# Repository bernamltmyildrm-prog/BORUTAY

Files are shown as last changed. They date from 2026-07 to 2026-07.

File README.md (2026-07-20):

<p align="center">
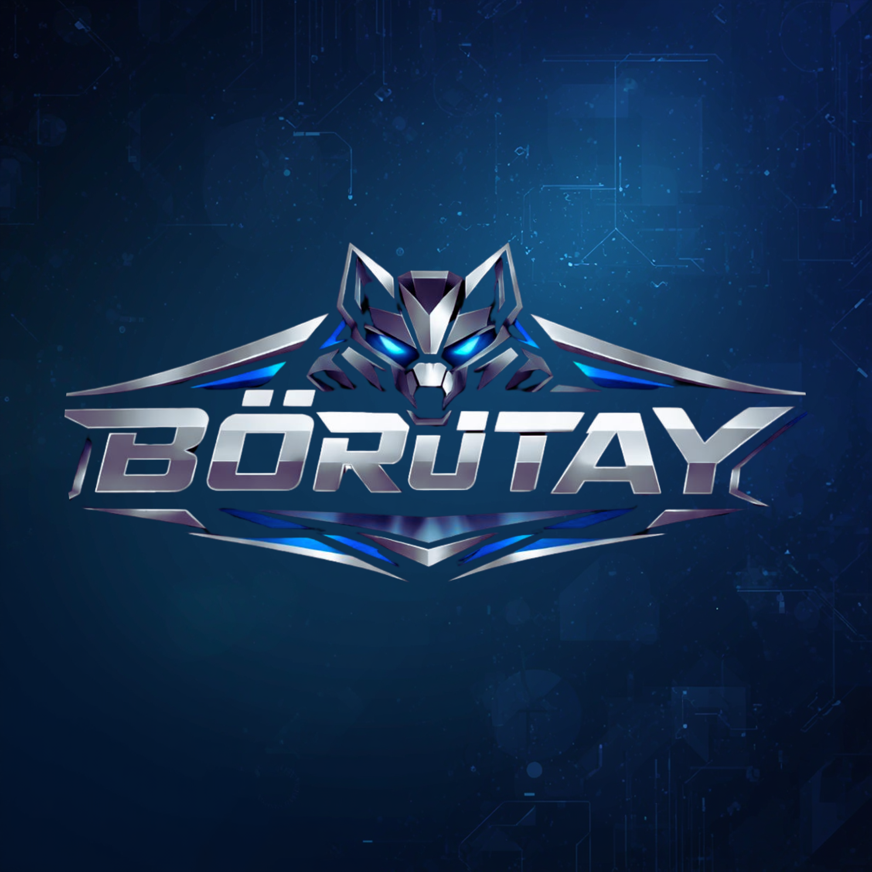
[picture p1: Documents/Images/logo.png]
  
</p>

<h1 align="center">
BÖRÜTAY
</h1>

<p align="center">
Hybrid Quadruped Robot Platform for Disaster Response and Autonomous Robotics
</p>

<p align="center">















</p>

---

# Overview

**BÖRÜTAY** is a modular hybrid quadruped robotic platform developed by the **BÖRÜTAY Team** at **OSTİM Technical University**.

The project has been developed as a research and development platform capable of operating in disaster response scenarios while serving as a flexible testbed for robotics, embedded systems, autonomous navigation and intelligent control algorithms.

The current version features a **2-DOF quadruped architecture** powered by **Raspberry Pi 5**, providing stable walking, real-time monitoring and wireless remote operation.

The next generation of BÖRÜTAY is currently under development and will include:

- 3-DOF Leg Architecture
- Wheel-Leg Hybrid Mobility
- Robotic Arm
- Deneyap Controller Integration
- RFID Module
- OLED Display
- micro-ROS Distributed Architecture
- AI Assisted Navigation

---

## Robot Platform

<p align="center">
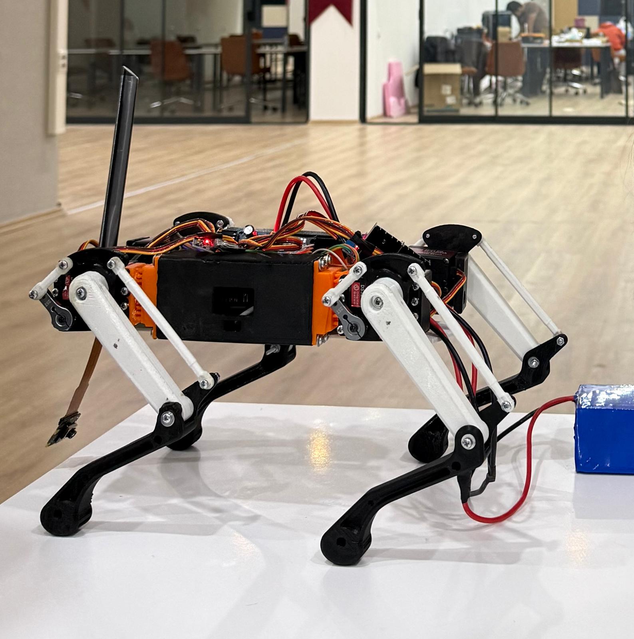
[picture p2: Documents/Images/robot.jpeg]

</p>

---

# Project Objectives

BÖRÜTAY has been designed with the following engineering objectives:

- Develop a modular quadruped robotic platform.
- Support disaster response operations.
- Provide reliable wireless teleoperation.
- Implement embedded Linux based robotic control.
- Integrate computer vision capabilities.
- Develop scalable embedded hardware architecture.
- Prepare the platform for future autonomous navigation.
- Establish a flexible software architecture for future robotic extensions.

---

# Current Features

- ✅ 2-DOF Quadruped Walking
- ✅ Raspberry Pi 5 Main Controller
- ✅ MQTT Communication
- ✅ Live Camera Streaming
- ✅ PyQt6 Ground Control Station
- ✅ Inverse Kinematics
- ✅ Servo Calibration
- ✅ Stable Trot Gait
- ✅ Real-Time Robot Monitoring
- ✅ Modular Software Architecture

---

# Future Features

- 🚧 3-DOF Leg Upgrade
- 🚧 Wheel Assisted Locomotion
- 🚧 Robotic Arm
- 🚧 RFID System
- 🚧 OLED Status Display
- 🚧 Deneyap Controller
- 🚧 micro-ROS
- 🚧 Autonomous Navigation
- 🚧 Object Detection
- 🚧 SLAM
- 🚧 AI Based Decision Making

---

# Hardware

The BÖRÜTAY platform has been designed with a modular hardware architecture that allows new sensors and actuators to be integrated without major software modifications.

## Main Computing Unit

- Raspberry Pi 5
- Raspberry Pi OS (64-bit)
- Python 3

## Embedded Controller (Planned)

- Deneyap Kart
- micro-ROS Node
- Peripheral Management

## Servo Control

- PCA9685 16-Channel PWM Driver
- DS3218 High Torque Digital Servo Motors

## Wireless Communication

- Dual MikroTik RouterBOARD Metal 52ac
- Wi-Fi Communication
- MQTT Protocol

## Vision System

- Raspberry Pi Camera Module

Future Vision Features:

- YOLO Object Detection
- Human Detection
- Obstacle Detection
- Autonomous Tracking

## Sensors

Current

- Pi Camera

Future

- IMU
- RFID Reader
- OLED Display

## Future Mobility

- Wheel Modules
- Robotic Arm
- DC Gear Motors

---

# Software Stack

The software architecture is fully modular, allowing each subsystem to be developed independently.

| Layer | Technology |
|---|---|
| Operating System | Raspberry Pi OS |
| Programming Language | Python |
| GUI | PyQt6 |
| Communication | MQTT |
| Broker | Mosquitto |
| Computer Vision | OpenCV |
| Motion Control | Inverse Kinematics |
| Servo Driver | PCA9685 |
| Future Middleware | micro-ROS |

---

# Repository Structure

```text
BORUTAY
│
├── CAD
│   ├── SolidWorks
│   ├── STL
│   ├── Assembly
│   └── Render
│
├── Documents
│   ├── Graduation_Project
│   ├── TEKNOFEST
│   └── Images
│
├── GUI
│
├── quadruped_pi
│   ├── main.py
│   ├── config.py
│   ├── quadruped.py
│   ├── gait.py
│   ├── leg.py
│   ├── hardware.py
│   ├── robot_listener.py
│   ├── camera_stream.py
│   ├── fake_gyro.py
│   └── utils.py
│
├── README.md
├── LICENSE
└── .gitignore
```

---

# Software Architecture

```
          Ground Control Station
                 (PyQt6 GUI)
                      │
                      │ MQTT
                      ▼
              Raspberry Pi 5
         ┌──────────┼──────────┐
         │          │          │
     Camera      Motion      Hardware
     Module      Control      Driver
         │          │          │
     OpenCV     IK Solver   PCA9685
         │          │          │
         └──────────┼──────────┘
                    │
              Servo Motors
```

---

# Future Embedded Architecture

```
           Ground Control Station
                    │
                 MQTT Broker
                    │
             Raspberry Pi 5
                    │
              micro-ROS Bridge
                    │
             Deneyap Controller
          ┌────────┼─────────┐
          │        │         │
      DC Motors  RFID      OLED
          │
     Robotic Arm
```

---

# Mechanical Design

Current Platform

- 2 Degrees of Freedom per Leg
- 8 Servo Motors
- Aluminum Mechanical Structure
- Modular Body Design

Future Platform

- 3 Degrees of Freedom per Leg
- 12 Servo Motors
- Wheel-Leg Hybrid Mobility
- Integrated Robotic Arm
- Improved Payload Capacity

---

# Communication

Current Communication

- MQTT
- Wi-Fi
- Raspberry Pi Camera Streaming

Future Communication

- micro-ROS
- ROS2 Topics
- Distributed Embedded Nodes
- Autonomous Robot Services

---

# Motion Control

BÖRÜTAY employs a modular locomotion system based on inverse kinematics and gait generation algorithms.

The current locomotion controller has been designed to provide smooth and stable walking while maintaining a lightweight software architecture that can easily be extended for future robotic capabilities.

## Current Motion Features

- Forward / Backward Walking
- Left / Right Turning
- Stand Mode
- Idle (Crouch) Mode
- Servo Calibration
- Smooth Motion Profiles
- Trot Gait
- Adjustable Step Height
- Adjustable Step Length
- Adjustable Gait Period

## Future Motion Features

- 3-DOF Leg Kinematics
- Dynamic Walking
- Terrain Adaptation
- Hybrid Wheel-Leg Motion
- Self Balancing
- Autonomous Locomotion

---

# Inverse Kinematics

Each leg is independently controlled using inverse kinematics.

Current implementation computes:

- Hip Joint Angle
- Knee Joint Angle

Future implementation:

- Hip Roll
- Hip Pitch
- Knee
- Full 3-DOF Kinematics
- Body Pose Compensation

---

# Computer Vision

The Raspberry Pi Camera provides real-time image streaming to the Ground Control Station.

Current capabilities include:

- Live Video Streaming
- Low Latency Monitoring
- Remote Camera View

Future capabilities include:

- Object Detection (YOLO)
- Human Detection
- Obstacle Detection
- QR / AprilTag Recognition
- Autonomous Target Tracking
- Visual Navigation

---

# Ground Control Station

A custom-developed Ground Control Station allows the operator to remotely monitor and control the robot.

Main Features

- Live Camera Stream
- MQTT Communication
- Motion Commands
- Robot Status
- Speed Adjustment
- Stand / Idle Control
- IMU Monitoring (Simulation)
- Object Detection Window
- System Start Function

---

# Ground Control Station Interface

<p align="center">
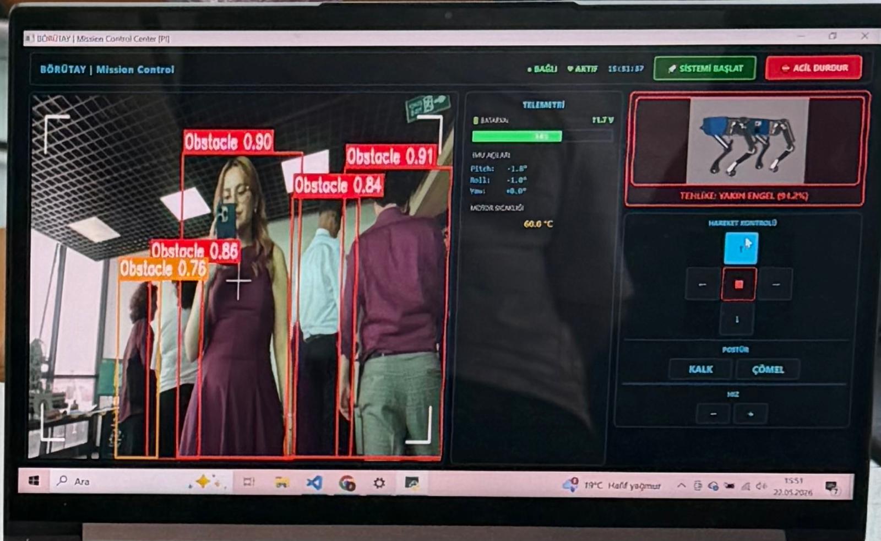
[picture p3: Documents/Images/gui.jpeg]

</p>

The graphical user interface was developed using **PyQt6** and communicates with the Raspberry Pi over the MQTT protocol.

---

# Project Gallery

## Team

<p align="center">
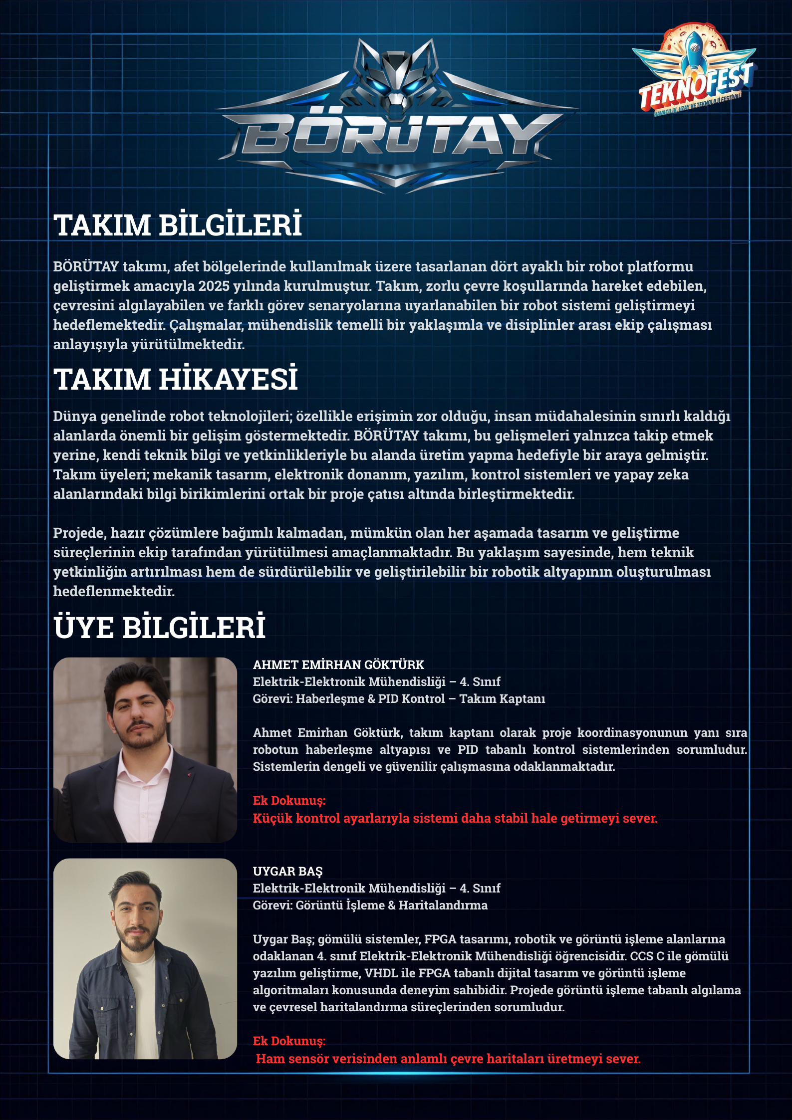
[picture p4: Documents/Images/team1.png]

</p>

<p align="center">
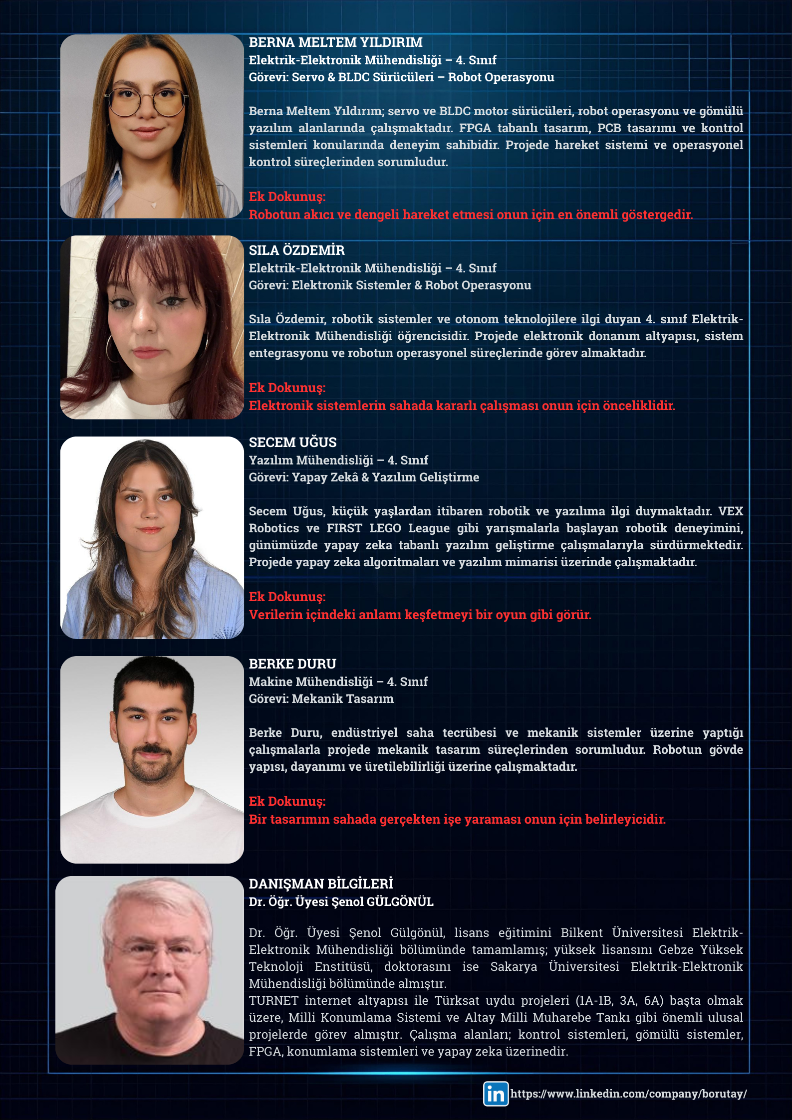
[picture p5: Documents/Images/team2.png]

</p>

---

## Exhibition

The BÖRÜTAY project was presented during the **OSTİM Technical University Graduation Projects Exhibition**, demonstrating the successful integration of mechanical design, embedded systems, wireless communication and quadruped locomotion into a single robotic platform.

The exhibition provided an opportunity to showcase the current capabilities of the platform while collecting valuable feedback for future development.

---

# Installation

Clone the repository:

```bash
git clone https://github.com/bernamltmyildrm-prog/BORUTAY.git
```

Navigate to the project directory:

```bash
cd BORUTAY
```

Install the required Python packages:

```bash
pip install -r requirements.txt
```

---

# Running the Project

## Raspberry Pi

Start the MQTT listener:

```bash
python3 robot_listener.py
```

Start the camera stream:

```bash
python3 camera_stream.py
```

---

## Ground Control Station

Launch the GUI:

```bash
python main.py
```

Once the **System Start** button is pressed, the GUI establishes communication with the Raspberry Pi, activates the robot control interface and starts receiving telemetry and live camera data.

---

# Project Workflow

```
Power ON
    │
    ▼
Connect Raspberry Pi
    │
    ▼
Start robot_listener.py
    │
    ▼
Start camera_stream.py
    │
    ▼
Launch Ground Control Station
    │
    ▼
Press "System Start"
    │
    ▼
MQTT Communication Established
    │
    ▼
Robot Ready
```

---

# Development Roadmap

## Phase 1 — Completed

- [x] Mechanical Design
- [x] Electronic Design
- [x] Raspberry Pi Integration
- [x] Servo Control
- [x] Inverse Kinematics
- [x] Trot Gait
- [x] Camera Streaming
- [x] MQTT Communication
- [x] Ground Control Station
- [x] Graduation Project Prototype

---

## Phase 2 — In Progress

- [ ] 3-DOF Leg Upgrade
- [ ] New Mechanical Design
- [ ] Improved Stability
- [ ] Wheel Integration
- [ ] Robot Arm
- [ ] Deneyap Controller
- [ ] RFID Module
- [ ] OLED Display
- [ ] micro-ROS Integration

---

## Phase 3 — Future Development

- [ ] Autonomous Navigation
- [ ] SLAM
- [ ] Visual Navigation
- [ ] Object Detection
- [ ] AI Decision System
- [ ] Autonomous Mission Planning
- [ ] Multi-Robot Communication

---

# Team

| Team Member | Responsibility |
|---|---|
| **Berna Meltem Yıldırım** | Embedded Systems • Raspberry Pi • MQTT Communication • Servo Control • System Integration |
| **Ahmet Emirhan Göktürk** | Motion Control • Control Algorithms • PID |
| **Uygar Baş** | FPGA • Embedded Systems • Low-Level Software |
| **Sıla Özdemir** | Electronics Design • PCB • Power Electronics |
| **Seçem Uğuş** | Software Engineering • GUI Development |

---

# Academic Advisor

**Dr. Şenol Gülgönül**

Department of Electrical and Electronics Engineering

OSTİM Technical University

---

# Acknowledgements

The BÖRÜTAY Team would like to express sincere gratitude to:

- **OSTİM Technical University**
- **Department of Electrical and Electronics Engineering**
- **Dr. Şenol Gülgönül** for his continuous guidance and academic support throughout the project.
- **OSTİMTech Technology Transfer Office (TTO)** for their valuable support during the development process.

Their encouragement and contributions have played an important role in bringing this project to its current stage.

---

# Contributing

Contributions, suggestions and feedback are always welcome.

If you would like to improve BÖRÜTAY, feel free to open an issue or submit a pull request.

---

# Support the Project

If you find this project interesting or useful, consider giving it a ⭐ on GitHub.

Your support motivates our team and encourages future development.

---

# Connect With Us

Stay connected with the **BÖRÜTAY Team** and follow our journey in robotics, embedded systems, and autonomous technologies.

<p align="center">

<a href="https://www.linkedin.com/company/borutay">

</a>

</p>

---

# License

This project is licensed under the **MIT License**.

See the **LICENSE** file for more information.

---

<p align="center">

## BÖRÜTAY

### *Inspired by our heritage. Engineered for the future.*

**Quadruped Robotics • Embedded Systems**

</p>

<p align="center">

Developed by the **BÖRÜTAY Team**

OSTİM Technical University

</p>

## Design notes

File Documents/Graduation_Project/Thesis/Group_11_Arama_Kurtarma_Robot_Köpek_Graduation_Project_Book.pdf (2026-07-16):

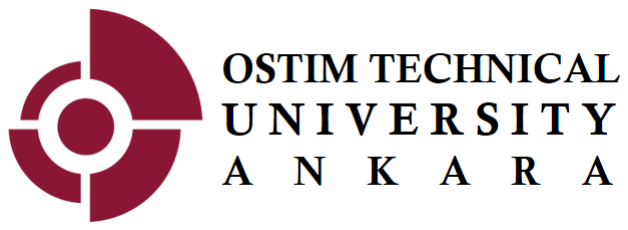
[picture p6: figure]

T.C.

## OSTIM TECHNICAL UNIVERSITY Faculty of Engineering

### Department of Electrical and Electronics Engineering

# Design and Implementation of a Search and Rescue Robot Dog for Disaster Areas

## (Graduation Project I)

### 210202023 Uygar BAŞ 210202015 Sıla ÖZDEMİR 210202009 Berna Meltem YILDIRIM 210202003 Ahmet Emirhan GÖKTÜRK

## Dr. Şenol GÜLGÖNÜL

### December 2025 ANKARA

T.C.

## OSTIM TECHNICAL UNIVERSITY Faculty of Engineering

### Department of Electrical and Electronics Engineering

# Design and Implementation of a Search and Rescue Robot Dog for Disaster Areas

## (Graduation Project I)

### 210202023 Uygar BAŞ 210202015 Sıla ÖZDEMİR 210202009 Berna Meltem YILDIRIM 210202003 Ahmet Emirhan GÖKTÜRK

## Dr. Şenol GÜLGÖNÜL

### December 2025 ANKARA

i

GRADUATION PROJECT APPROVAL FORM

The undergraduate graduation project titled “[Afet Bölgelerinde Arama Kurtarma Amaçlı Robot Köpek Tasarımı ve Uygulaması]”, prepared by [Uygar BAŞ, Sıla ÖZDEMİR, Berna Meltem YILDIRIM, Ahmet Emirhan GÖKTÜRK] under the supervision of

[ Dr. Şenol GÜLGÖNÜL] was examined and accepted as an Undergraduate Graduation Project in terms of its scope and quality.

Supervisor | : Dr. Şenol GÜLGÖNÜL
Jury member 1 | : Dr. Burak YENİPINAR
Jury member 2 | : Prof. Dr. Sinan KIVRAK
Head of the Department | : Prof. Dr. İsmail Hakkı ALTAŞ

ii

FOREWORD

This graduation project was prepared by the students of the Department of Electrical and Electronics Engineering, Faculty of Engineering, OSTIM Technical University, within the scope of Graduation Project I. The project focuses on the design and implementation of a quadruped robot dog intended for search and rescue operations in disaster areas.

We would like to take this opportunity to express our thanks to Asst. Prof. Dr. Senol GULGONUL, our project supervisor and mentor, for the valuable support and guidance that he provided us during the development of our final project. His knowledge and encouragement were critical to successfully completing our graduation project.

We would also like to thank Professor Dr. Ismail Hakkı ALTAS, Head of the Electrical and Electronics Engineering Department, for providing us with an outstanding academic environment that enabled us to successfully complete our graduation project.

Finally, we would like to express our heartfelt appreciation to all our families for their continuous support, patience, and encouragement throughout our academic journey, including the completion of our final project.

December 2025

Uygar BAŞ
Sıla ÖZDEMİR
Berna Meltem YILDIRIM
Ahmet Emirhan GÖKTÜRK

iii

CONTENTS

1.1.1. Global and Regional Impacts of Natural Disasters and the Need for Search and Rescue..1
1.1.2. Evolution of Mobile Robotic Systems: Transition from Wheeled to Legged Architectures

iv

v

vi

ABSTRACT
Search and rescue operations are greatly challenged by natural disasters, such as earthquakes, due to collapsed structures, unstable terrain, and limited access. The traditional rescuer, human, must take many risks and face time constraints when performing rescues in these types of environments. Robotic systems that can safely and effectively operate in abnormal, hazardous, and/or otherwise challenging environments are becoming more desirable in the field.

In this graduation project, the design and implementation of a quadruped search and rescue robot dog for disaster areas is presented. The proposed robot is designed to move effectively on uneven and debris-filled surfaces, where wheeled or tracked robots are insufficient. Owing to its four-legged structure, the robot is capable of maintaining balance and mobility in challenging terrains commonly encountered in disaster zones.

The prototype is composed of three functional categories: mechanical systems, electronics, and embedded systems; these are combined, through integration, to develop one prototype. The stability of the actuators (legs) enables the robot to maintain a consistent position and to walk in a smooth manner. In order to achieve a walking robotic device with balanced mobility, engineers used methods based on PID control. The prototype contains many different types of sensors, including an inertial measurement unit, a Lidar sensor, a camera, and a microphone, which will allow the robot to distinguish potential survivors from ordinary people. All of the sensor readings will be processed in real-time; therefore, except for occasional manual intervention, all tracking will occur automatically. Specific signal detection and locations will be sent wirelessly to a remote command and control facility.

In both cases of being semi-autonomous and fully autonomous, there will be a system with a level of flexibility based on each respective mission. The overall purpose of this project involves increasing the efficiency of search and rescue, improving safety for personnel, and still providing a means for increasing situational awareness in disaster areas. The developed prototype will be a low-cost, easily manufactured robotic solution that supports future research and development in disaster response robotic solutions.

vii

SYMBOLS AND ABREVIATIONS

AI | Artificial Intelligence
CAD | Computer-Aided Design
DOF | Degree of Freedom
IK | Inverse Kinematics
IMU | Inertial Measurement Unit
I2C | Inter-Integrated Circuit

LiDAR Light Detection and Ranging

Li-Po | Lithium-Polymer Battery
MCU | Microcontroller Unit
PID | Proportional–Integral–Derivative
PWM | Pulse Width Modulation
SPI | Serial Peripheral Interface

UART Universal Asynchronous Receiver–Transmitter

W_total Total weight of the robot (N)

W_leg | Load/weight per leg (N)
m | Mass (kg)
g | Gravitational acceleration (m/s^2)
F_leg | Force acting on one leg (N)
F | Applied force (N)
T, τ | Torque (N·m)
r | Lever arm / moment arm (m)
L | Distance from joint axis to load point (m)
σ | Normal stress (Pa)
M | Bending moment (N·m)
c | Distance from neutral axis (m)
I | Area moment of inertia (m^4)
A | Cross-sectional area (m^2)
x, y | Foot position coordinates (m)
l1, l2 | Link lengths (e.g., femur and tibia) (m)

viii

θ1, θ2 | Joint angles (rad or deg)
m_i | Mass of component i (kg)

x_i, y_i Position of component i (m)

x_cm, y_cm Center of mass coordinates (m)

P_total | Total power consumption (W)
P_i | Power of component i (W)
E | Energy (Wh or J)
t | Time / operating duration (h or s)
I_total | Total current consumption (A)
I_servo | Current per servo / servo group (A)

I_control Control electronics current (A)

C | Battery capacity (Ah)

f_control Control loop frequency (Hz)

T_control Control loop period (s)

ix

THE LIST OF FIGURE

Figure 2.3. Calculation

Figure 2.4. Servo Motors and Raspberry Pi 5

Figure 2.5. Jetson Nano and Sensors

Figure 2.8.Wi-fi Modul and Jetson Nano

Figure 3.1. Overall CAD model of the quadruped robot

Figure 3.2. Side view of the robot showing overall height and leg geometry

Figure 3.3. Leg segment configuration illustrating coxa, femur, and tibia

Figure 3.4. Waveshare Jetson Orin NX 16GB AI kit (WiFi)

Figure 3.5. Raspberry Pi 5 single-board computer

Figure 3.6. PCA9685 16-Channel I2C PWM servo driver board

Figure 3.7. Arducam 2.3 MP AR0234 camera module

Figure 3.8.RPLIDAR A2M8 360° LiDAR sensor

Figure 3.9. MG996R metal-gear digital servo motor

Figure 3.10. Power distribution and battery system architecture

Figure 3.11.System hardware layout and internal component placement within the chassis

Figure3.12. The TP-Link Archer T4U dual-band Wi-Fi adapter

Figure 3.13. Software architecture and data flow diagram

Figure 4.1. Simplified kinematic representation of a single robot leg (links and joints)

Figure 4.2. Coordinate frame and foot position definition used in inverse kinematics

Figure 4.3. Geometric inverse kinematics diagram for a two-link planar leg model

Figure 4.4. Inverse kinematics algorithm flow diagram (input: foot position, output: joint

angles)

Figure 4.5. Example foot trajectory and corresponding joint angle variation (theoretical

output)

x

THE LIST OF TABLES

Table 1.1. Work–Time Schedule

Table 1.2. Risk Analysis and Alternative Plans

Table 1.3. Distribution of Work Packages

Table 3.1. Component List and Economic Analysis

THE LIST OF EQUATIONS

Equation (1): Load Distribution per Leg

Equation (2): Static Load Calculation per Leg

Equation (3): Servo Motor Torque Equation

Equation (4): Required Joint Torque Calculation

Equation (5): Bending Stress Equation

Equation (6): Inverse Kinematics Equation for Joint Angle θ₂

Equation (7): Inverse Kinematics Equation for Joint Angle θ₁

Equation (8): Total Current Consumption Equation

Equation (9): Battery Operating Time Estimation

Equation (10): Inverse Kinematics Intermediate Variable (D)

1.INTRODUCTION

### 1.1. General Information

### 1.1.1. Global and Regional Impacts of Natural Disasters and the Need for Search

and Rescue

Natural disasters have been part of human existence since there have been humans-

causing great turmoil both socially and economically, as well as demographically.

While you cannot stop a natural disaster from occurring, you can lessen its effect.

Increased frequency and destructiveness of natural disasters are a direct result of factors

such as global warming, urban sprawl, increased population, and tectonic activity. The

total cost to the world from natural disasters in the last 20 years has been in the trillions

of dollars according to the United Nations Office for Disaster Risk Reduction (UNDRR).

In addition, many hundreds of millions of people have died or lost their homes due to

natural disasters. Because of its geographical location on the Alpine-Himalayan seismic

belt, Türkiye experiences the most seismic activity. The presence of three major fault

lines- North Anatolian Fault, East Anatolian Fault, West Anatolian Fault contributes to

over 90% of Türkiye’s land surface being at risk for earthquakes. Recent Turkish history

such as the 1999 Marmara earthquake, the 2011 Van earthquake and most recently, the

Kahramanmaraş earthquakes of February 6, 2023 show the real vulnerability of the

building stock of Türkiye and the importance of the post-disaster response process.

Labeled the "disaster of the century," the Kahramanmaraş earthquakes have a much

wider geographical range than most previous earthquakes along with an extensive level

of devastation resulting from extreme winter weather that overwhelmed conventional

search and rescue efforts.

One of the main principles in the disaster response process is the "Golden Hours"

factor. The first seventy-two (72) hours immediately following a disaster is the time

period that provides victims under rubble with the highest probability of survival.

Finding victims under rubble during this time frame minimizes life-threatening

conditions such as hypothermia, dehydration, blood loss, and Crush syndrome.

Unfortunately, chaotic collapse of reinforced concrete structures that create impassable

rubble piles, minimize existing survival avenues (triangles of life), create unstable

building components, and pose threats from aftershocks present barriers for search and

rescue teams to access quickly and safely. Moreover, search and rescue are showing diminishing returns as intervention based solely on human effort deteriorates through

physical fatigue, psychological trauma, and safety concerns, which eventually decreases

the rescue effectiveness.

The next step is the use of robotic technology and automated systems. Search and

Rescue Robots are employed to provide services such as mapping, exploration,

audio/video communications, and transporting of medical supplies. They can be sent

into locations that are either unsafe for people to enter or too hazardous for them. These

automated systems gather real-time, precise and useful information, thus limiting the

uncertainty faced by the teams making decisions or conducting rescues following a

disaster strike.

### 1.1.2. Evolution of Mobile Robotic Systems: Transition from Wheeled to

Legged Architectures

When looking at how search and rescue robots have evolved, the first thing to notice

is that "mobility" was the main focus for technology. Search and rescue robots were

created mainly with wheeled and tracked designs.

Wheeled Robots: The main advantages of these vehicles are their high speed, energy

efficiency, and controllability on flat, hard surfaces (e.g., asphalt, concrete, etc.).

However, their mobility is impeded upon encountering objects with a size greater than

that of the wheels or at the point of low-friction ground surfaces (e.g., mud, sand).

Objects like iron bars, piles of debris, and steps/ledges that are common in debris fields

represent major obstacles to wheeled robot navigation.

Tracked Robots: Robots equipped with tank-style locomotion have a much larger

area of contact with the ground, thereby providing them with increased traction. Track-

type robots have been developed to be utilized in military or search and rescue operations

(e.g., the PackBot), and they have been shown to traverse stairs and navigate rougher

terrain more effectively than wheel-type robots. Nevertheless, although track-type robots

utilize the same principle of maintaining "continuous contact with the ground," they have

a high chance of getting stuck in crevasses, on steep terrain, or on piles of debris with

complex and irregular shapes (i.e., unstructured terrain). Furthermore, track-style robots

are much heavier than their wheel counterparts, thus requiring much more energy to

operate.

Investigating living organisms in their natural habitats indicates that the best approach

to moving through challenging environments is to have "legs". Legged robots can contact

the ground at a point, which allows them to use even the tiniest safe footfalls available

in a given area as leverage to jump over obstacles that wheels and tracks cannot traverse,

climb steep staircases, manoeuvre through narrow corridors, and maintain their balance

while adjusting their posture on uneven terrain.

Among legged systems, the quadruped robot is the architecture that combines the

highest level of balance with the highest level of speed. Quadruped robots have better

static stability than bipedally (humanoid) robots (because they can keep three feet on the

ground while the fourth foot is in the air). Moreover, quadruped robots can achieve a

greater speed and provide a lower mechanical complexity compared to six or eight-

legged (hexapod/octopod) robots.

For this reason, quadruped robots have become widely accepted as the platforms that

are the best "adapted to terrain" and used in contemporary search-and-rescue literature.

### 1.1.3. Dynamics of Quadruped Robots and Control Theory

Quadruped robot design and control are much more difficult engineering problems

than those for wheeled robots. A wheeled vehicle can be statically stable when the

motors have been turned off; however, the legged robot requires constant (active) control

to maintain balance while standing, walking or running. Therefore, the control issue has

two main components: Kinematics and Dynamics.

Kinematic Modeling: Calculating the position of the robot's limb (leg) end-effectors

in reference to the robot's center of gravity.

Finding the foot tip's position based on joint angles would involve using forward

kinematics.

To calculate the joint motor angles that the foot tip should be at for it to reach a desired

position (i.e., the next step point), we use inverse kinematics. In our application, we will

have to perform inverse kinematics calculations thousands of times per second for every

step of the robot in order to send angle commands to the motors.

Balance Control and PID: In order for the robot to stay upright as it moves around, we

need to keep the Center of Mass (CoM) under control. When stationary, we need to keep

the CoM within the area supported by its feet on the ground; however, as soon as the

robot starts to make moves outside of the area supported by its feet (i.e., when the robot

runs or jumps), other forces become important. Some of these forces are referred to as

Inertial Forces, and some of the terms we use to describe them include Zero Moment

Point (ZMP). To keep control over the balance of the robot, PID (Proportional-Integral-

Derivative) Controllers are used for controlling balance. The PID algorithm uses

accelerometer and gyroscope data from the robot IMU (Inertial Measurement Unit) to

identify the robot's current roll and pitch angles.

P (Proportional): Apply a reverse force proportional to how much the robot has tilted.

I (Integral): If the robot constantly stands tilted to one side (steady-state error), correct

this over time.

D (Derivative): When an impact occurs suddenly, assess the tilt's speed, and then react

by dampening any oscillation that may have resulted. Tuning all three parameters

correctly will guarantee the body of the robot will remain stable and parallel with the

ground, even when traversing an uneven surface like a stone.

### 1.1.4. Perception, Mapping, and Artificial Intelligence

A modern state-of-the-art search-and-rescue robot needs to be an autonomous unit

that perceives its environment and can independently make decisions and carry out those

decisions. In instances where the communication infrastructure in a disaster zone has

been destroyed, and there are large pieces of concrete preventing the use of radio waves,

it is crucial for the robot to be able to continue its search-and-rescue mission without

having to rely on a connection to the operator. Therefore, the primary elements that

provide this ability to be autonomous are Perception and AI (Artificial Intelligence).

LIDAR (Light Detection and Ranging): The sensor technology utilizing Laser

Based (Lidar) Sensor creates 3D Maps of your surroundings with Laser Pulses. The Lidar

will identify the surrounding environment of the robot including walls, voids, and objects

around the robot with a centimeter-level precision. The data gathered from the Lidar will

then run SLAM (Simultaneous Localization and Mapping) Algorithms; which means that whilst the robot builds a map of an unfamiliar environment, it can also tell where on

that built map it is located.

Image Processing and Deep Learning: Lidar can detect the shape of an object but

cannot determine what it is. This is where a camera and AI will help us. Our project is

using powerful embedded computers like the NVIDIA Jetson Nano to process real-time

camera images. Deep learning models for object recognition (e.g. YOLO- You Only

Look Once) have been trained using debris images to identify specific patterns such as

a "human body", "hand", or "thermal signal of life".

Sensor Fusion: Sometimes data from just one sensor can give you an inaccurate

picture (for example, dust can cause a camera to not be able to see) but by combining

(i.e., fusing) all the data from four sensors (Lidar, Camera, IMU, and Microphone), the

robot will get a better understanding of where and what is happening. If the robot hears

a sound saying "help," it will turn toward it, confirm there is a clear path with Lidar, and

visually confirm the victim with a camera.

### 1.1.5. Project Objective and Unique Design Approach

This thesis aims to design and create a prototype for a low-cost, non-industrial

quadruped robot (a domestic robot dog) to serve the needs described above and assist in

disaster scenarios. The prohibitive costs of existing industrial robot dogs (such as Boston

Dynamics Spot) limit the general use of this technology. This project supports the

philosophy of "Accessable Technology" and will produce the built mechanical

components of the robot using 3D Printing (Additive Manufacturing) technology.

The unique design approach of the project is based on the following fundamental

pillars:

1. Modular and Repairable Mechanics: The robot's body and leg parts are

designed to be produced even in the field. A broken part can be printed and

replaced within minutes.

2. Hybrid Processor Architecture: The Raspberry Pi/Microcontroller is used

for low- level motor control, while the Jetson Nano is utilized for high-level

artificial intelligence, computer vision, and image processing. Thus, the entire

system operates more efficiently as the respective tasks are delegated to the appropriate hardware platform based upon processing capabilities and

available resources.

3. Multi-Sensor Integration: By using Lidar, Stereo Camera, and Sound

Sensors together, the robot's "life detection" success under debris is

maximized.

This project is comprehensive R&D and draws on multiple engineering disciplines

including mechanical design, electronics hardware integration, embedded software and

Artificial Intelligence to be able to contribute technologically to the enhancement of

Disaster Response capabilities in Canada.

1.2.LITERATURE REVIEW

The Literature Review section analyzes the current state of national and international

research regarding Search and Rescue Robots (SRR), Quadruped Walking Mechanisms

(QWM), Balance Control Algorithms (BCA), and Sensor Fusion (SF). The analysis

includes both chronological and thematic approaches to the existing SRRs, QWMs,

BCAs, and SFs in order. The Literature Review establishes the scientific foundation for

this project, highlighting how the proposed SRR is different from those previously

researched.

1.2.1.Development of Quadruped Robots and Academic Studies
The earliest studies of quadrupedal robots can be traced back to the 1980's when Marc

Raibert created the MIT Leg Lab, pioneering the development of robotic robots that

would ultimately be an ancestor to modern day robotics. The first robots to walk

dynamically were developed using single leg systems (aka hoppers). The way these

robot's maintained their equilibrium was by constantly jumping. The studies conducted

by Raibert provided the basis for the further development of advanced robotic

technologies.

In their article titled "Development of Quadruped Walking Robots: A Review,"

Biswal et al. (2021) presented an extensive review of quadrupedal robots that have been

developed over the last 20 years. Within their review, they provided a detailed

comparison of various aspects of quadrupedal robot development, including kinematic structure (both mammalian and reptilian leg configuration), propulsion method (electric,

hydraulic, pneumatic), and control method. Biswal found that electric motors are more

appropriate for small to medium-sized quadrupeds regarding energy efficiency and

precision of control than hydraulic motors; however, he noted that because the hydraulic

motor has a significantly greater load-carrying capacity than the electric motor (i.e., the

Boston Dynamics BigDog), the stronger option may be best for larger robotics,

depending on the desired function. Because our project is for an exploration mission that

will be performed for search and rescue, and because we're creating a robotic quadruped

that will be portable, we are designing it with electric servo motors to be consistent with

Biswal's recommendations.

MIT has developed "Mini Cheetah," which is viewed in the literature as an important

milestone. The publication of Katz, Carlo, and Kim (2019) Mini Cheetah: A Platform

for Pushing the Limits of Dynamic Quadruped Control (Katz et al., 2019) includes

experimental tests showing dynamic movements (backflip, recovery after falling,

running.) The greatest innovation of the Mini Cheetah is in the development of their own

quasi-direct drive actuators for the legs. These motors provide a high torque density with

a very low gear ratio, thus producing compliance. The Katz study has also shown that

managing the legs of the robot should not only include position control, but also torque

and force control. In our project we will be using standard servo motors, due to budget

constraints, but will apply virtual spring-damper models in our software to try to provide

a similar elastic response to that of our prototype.

### 1.2.2. Balance Control Algorithms and Gait Planning

To traverse rough terrains effectively, the balance controller of a quadrupedal robot

requires a significant degree of balance and stability. To identify potential compensation

techniques for the quadrupedal robot's balance after it has sustained an external force

(e.g. over a stick), Sun et al. (2022), in their paper entitled, "Balance Control of a

Quadruped Robot Based on Foot Fall Adjustment" examined how to adjust the footfalls

of quadrupeds in reaction to a stimulus. The results were obtained using a combination

of the Model Predictive Control (MPC) and conventional Proportional- Integral-

Differential (PID) controllers. By being able to predict its future position, Sun's study

allowed for the prediction of possible loss of balance and the identification of ways for the robot to take preventive measures. An additional

key finding of this study was that to improve stability when walking on wet and/or

inclined surfaces, the foot tip forces should be optimised. Due to the limitations on

processing power related to our Jetson Nano/Raspberry Pi (as compared to the original

study), rather than using MPC-style methodologies with high processing loads, we chose

to use enhanced PID and Zero Moment Point (ZMP) approaches derived from Sun’s

work, but without the severe processing burden incurred by the use of the MPC approach.

Chen and Nguyen (2021), in "Adaptive Force-based Control for Legged Robots,"

describe a way of adapting a legged robot's control by using information about the

stiffness of the ground to modify the robot’s stiffness. The authors noted that when the

robot encounters a soft surface (e.g., sand, snow), the robot should increase its leg

stiffness (i.e., move more stiffly), while it should decrease its leg stiffness when walking

on a hard surface (i.e., move less stiffly). This method improved the energy efficiency

of the robot by 15%.

### 1.2.3. Sensor Fusion and Autonomous Navigation

Studies of the use of sensor fusion in the development of autonomous search and

rescue robots indicate that there is evidence supporting the importance of sensor fusion

for enabling robots to operate autonomously. Ko et al. (2022), in their article, "Lidar-

IMU Sensor Fusion- Based SLAM for Enhancing the Autonomous Navigation

Performance of a Search and Rescue Robot," indicated that in environments where the

visibility of Lidar is compromised due to smoke or dust, the use of Lidar only would not

provide adequate information, and therefore, IMU data (an Inertial Sensor) should

accompany Lidar data. The results from their studies demonstrated that utilizing the

Kalman Filter to combine the geometric map generated by Lidar with the orientation and

acceleration information generated by the IMU resulted in a reduction of positional error

to within centimeters of the actual position. The research discussed in this article formed

the basis for the use of both Lidar and IMU in conjunction with each other as well as in

combination with gmapping and hector_slam algorithms running through the Robot

Operating System (ROS).

### 1.2.4. Low-Cost and Open-Source Robot Projects

Not only have high-tech Lab robots been documented in the literature, but there are

also studies of affordable and basic Robots. According to the publication, 'The Low-Cost

Open Source Semi-Autonomous Quadruped Robot' by García-Cárdenas et al. (2020), a

Robotic Dog could be made entirely from 3D Printed components and Common Hobby

Servos. This publication has provided one of the most fundamental reference points for

our Project. Specifically, García-Cárdenas emphasised that while using low-cost servos

makes it difficult to control their torque limits and gear backlash, this issue can be

alleviated through proper Kinematic Design (Leverage Length Optimisation).

Additionally, the Stanford Dogs and Pupper projects of Stanford University have shown

how powerful Open-Source Hardware can be. Our Project is utilising an NVIDIA Jetson

Nano along with Image Processing and Artificial Intelligence capabilities, which will

convert the 'simple' Robotic vehicle (RC) into an autonomous Search and Rescue

Assistant.

### 1.2.5. Life Detection via Sound and Image Processing

The primary purpose of search and rescue robots is to locate missing persons.

According to Lamo and Bassy (2024), in "A Survey of Sound Source Localization and

Detection Methods," sound is the most accurate source of information if there isn't a

direct line of sight among the debris. They explored methods to determine Direction of

Arrival (DoA) through a microphone array. Conversely, in their research "AI on the

Road: NVIDIA Jetson-Nano Computer Vision", Popa et al. (2024) showed that Jetson

Nano can effectively run advanced models for image interpretation (e.g., YOLO and

SSD) in real-time using edge technology. Together, these papers provide the foundation

for our "perception layer" of our project's overall system. Our project represents an

innovative hybrid system that employs both sound processing and image processing

methodologies in one transportable mobile device.

1.2.6.The Project's Place and Distinctiveness in Literature
As a result of the literature review, it was observed that;
1. Existing industrial robots (Spot, ANYmal) are very expensive,
2. Academic robots (Mini Cheetah) are generally aimed at laboratory

environments,

3. Low-cost robots (Open Source projects) generally lack autonomy and

artificial intelligence features.

The goal of the study outlined in this thesis is to fill in the gaps that exist in the

literature associated with "Cost-Effective Hardware" and "Advanced Artificial

Intelligence." Our project is distinguished from other similar projects described in the

literature through the use of deep learning algorithms that process data collected from

sensors integrated into a simple mechanical structure 3D-printed at a reasonable price

point, using a combination of Lidar, stereo camera, and microphone, along with

processing equipment designed for use with Jetson Nano.

### 1.3. NOVELTY

Literature reviews, as well as the results of various industry research, suggest that all

current search-and-rescue robotic systems are divided into essentially two groups. At

one end of the spectrum, there are expensive, high-tech industrial robotic systems (like

those developed by Boston Dynamics, specifically their Spot platform) that are priced

well beyond the reach of most members of supply chains (typically ranging from $70,000

to $150,000) and therefore are very rarely found or utilized in today's search-and-rescue

operations. At the other extreme, there exists a second group of robotic systems

consisting of very low-cost hobbyist- type systems that typically provide extremely

limited processing power and very little autonomy.

The search-and-rescue robot for disaster zones that is described and developed within

this thesis is intended to be a new, innovative engineering solution that fills the void

between these two categories:

- The fundamental elements constituting the novelty of the project are detailed

below:

Cost-Effective and Sustainable Manufacturing Model:

This project developed the Mechanical Body and Walking Parts utilizing exclusively

the Additive Manufacturing (3D Printing) process, rather than the traditional methods of

production seen in industrial robotics. This approach reduces the cost of this robot to

approximately 5% of the costs associated with Industrial Robots; additionally, it

provides "Repairable in the Field." The ability to manufacture and replace a leg limb that

has been damaged in a disaster zone with a mobile 3D Printer on location offers the

opportunity of sustainable operations without needing to establish a system of logistical supply chains. This feature provides assurance of the sustainability and ongoing

operation of this project.

Hybrid Embedded System Architecture and Edge AI:

Numerous studies done by researchers use a single microcontroller for controlling

robots and to offload heavy processing operations onto a remote server or computer

(Cloud Computing) for efficient processing. When it becomes impossible to

communicate with a server remotely due to damage or other issues in a disaster area, the

possibility of processing data using remote servers becomes unreliable. As a solution to

this challenge, a hybrid framework was developed using both NVIDIA Jetson Nano

(High Level) and Raspberry Pi or an Alternative Microcontroller (Low Level) to

create the best of both worlds. The NVIDIA Jetson Nano will perform image recognition

locally via Edge AI without any Internet connection, and the Low Level Processor

(Microcontroller Unit) will provide control of motors and provide balancing

functionality in the range of milliseconds. Distributing these tasks between two

processors provides the most efficient and immediate response to any situation

encountered by the robot.

Multi-Layer Sensor Fusion for Life Detection:

Most current robotic systems use only one type of data to operate. In this project, we

present a multi-layered approach that combines visual (camera), spatial (Lidar) and

auditory (microphone array) sensing. For example, in situations when the robot does not

have visual access to its surroundings due to debris blocking its view, the robot’s ability

to locate the position of a call for help (sound source localization) using microphones

and then focus the camera and Lidar in that direction reduces the likelihood of false

positives related to identifying living victims.

Enhanced Control Algorithm for Dynamic Terrain Adaptability:

The non-precision torque fluctuation and gear backlash of low-cost servos present

challenges for gait control. An adaptive PID Controller was created that works in

conjunction with an inertial measurement unit (IMU) to provide software compensation

for these hardware challenges. The adaptive PID controller prevents the robot from

tipping during a foot slip or collapse of the ground, as the velocity of the centre of mass

can be transferred to the remaining leg within milliseconds.

### 1.4. METHOD

A systems engineering methodology has been utilized to manage and carry out this

project as defined by the systems engineering V-Model. The V-Model is a hierarchical

system engineering process used to document/ define a project through the various

phases of requirements definition, design and implementation, testing, and verification.

The project will consist of four major project phases as follows:

Phase 1: Mechanical Design and Kinematic Analysis,

Modeling: SolidWorks 3D CAD software was used to create the body and limb

components of the robot. In developing the design of the robot, we incorporated the

Center of Mass (CoM), which has to be located low to avoid tipping over when walking

over obstacles/debris, and also included an increase in the Range of Motion (RoM) for

the robot's legs to allow for the ability to climb stairs.

Analysis: Using ANSYS's Finite Element Analysis (FEA), the durability of the parts

was determined using stress concentra-tions that were assessed at the leg joints. The

results of the analysis were used to optimize the infill density for 3D printed parts.

Kinematics: The inverse kinematics model for the robot was developed using a

series of mathematical calculations to obtain a matrix equation that would calculate how

many degrees each joint motor needed to rotate in order for the robot's body to reach the

desired position (x, y, z).

Phase 2: Electronic Hardware Integration

Power System: The robot will be powered through the use of several lithium polymer

(Li- Po) batteries which provide very high current capabilities. The mechanical drive

train/battery pack is powered by a low voltage rating whereas the more sensitive

electronic components will be powered through voltage regulation devices (buck

regulators).

Communication: Sensors use I2C, microcontrollers communicate with UART, and

cameras and lidar operate through USB protocols. Telecommunications data will also be

sent from the robotics to the ground station using the 4G Module via Wireless

Communication and WiFi.

Phase 3: Software and Algorithm Development

Robot Operating System (ROS): Modularity is the main component of the software

framework being built using the Robot Operating System (ROS). All sensors and

actuators will operate as ROS nodes and communicate with one another.

Image Processing: Image processing methods are created using Python

programming language and OpenCV software library. Pre-trained YOLOv5 and/or

MobileNet SSD models for detecting humans will be optimized with TensorRT and

executed via Jetson Nano.

Balance Control: Euler angles (Roll, Pitch, Yaw) obtained from an IMU sensor will

be used to generate real-time control signals for the motors via a PID feedback loop.

Phase 4: Test and Verification

Simulation: Prior to the robot being built physically, the design of the robot will be

simulated within a Gazebo environment to allow for gait algorithms to be evaluated in a

controlled setting.

Field Tests: Once the first prototype of the robot is manufactured, it will be subjected

to a simulated debris test using a synthetic training track consisting of inclined ramps,

rocky surfaces, and stairs, in a laboratory setting. Testing will measure key performance

metrics (distance traveled before tipping over, battery run time, image latency, and

detection accuracy rate) for the respective testing parameters.

### 1.5. IMPACT

Upon successful implementation of the project, the anticipated technical, economic,

and social deliverables will be as follows:

### 1.5.1. Social and National Security Impact

Türkiye is situated in an earthquake-prone region, thereby making search-and-rescue

technology a necessity. The robotic technology developed as part of this research project

will enable search-and-rescue operations to be conducted prior to human personnel

entering hazardous areas, damaged buildings, and/or tunnels that may be leaking gas (to

conduct "vanguard reconnaissance"). By advancing the search-and-rescue operation

prior to the arrival of human personnel, it is expected that due to the earlier identification

of victims prior to entering the area, (1) the safety of search-and-rescue personnel will be enhanced; (2) the likelihood of locating victims trapped beneath debris will improve

based on the ability to intervene in the first 96 hours after an earthquake; and (3) an

increase in operational efficiency will occur by eliminating wasted response time in

searching for victims in "hot zones."

### 1.5.2. Economic and Commercial Impact

Currently, search-and-rescue robots (produced by foreign manufacturers) used by

AFAD (the Turkish Emergency Services) and/or Fire Brigade units/Authorities consume

a substantial amount of foreign currency; this project will enable Türkiye to manufacture

its search-and-rescue robots using local resources at significantly lower costs, thereby

improving Türkiye's economy through the reduction of reliance on foreign products. The

prototype developed through this project has excellent commercial potential and may be

used in a variety of civilian and non-civilian applications, including the Defense

Industry, the Mining Sector, and/or the Industrial Inspection sector.

### 1.5.3. Academic and Scientific Impact

The information gained from the project (i.e., performance of sensor fusion and

strength tests on 3D printed parts) will add to the body of knowledge within the academic

area of Mechatronics and Robotics. The findings will be reported in the form of papers

presented at both domestic and foreign conferences and will also provide an example of

"applied robotics" for other students attending the university. In addition, the Embedded

System, Artificial Intelligence, and Mechanical Design skills gained through this project

will assist the country in meeting its demands for qualified engineers.

### 1.6. STANDARDS

The International/Electricity standards provide an overview's Reliability, Safety and

Conformity through Design and Build of a Robotic Society.

ISO 13482 (Robots and robotic devices — Safety requirements for personal care

robots): The design of a robot must include Safety Procedures (Collision Avoidance) to

reduce loss of life while the robot responding to requirements to Evacuate Victims safely.

IEC 62133 (Secondary cells and batteries containing alkaline or other non-acid

electrolytes): Battery Management Systems will ensure that Lithium Ion Batteries are

protected during Charge/Discharge cycles and against Overheating and Short Circuits.

IEEE 802.11 (Wireless LAN Standards): A robot must have Wireless (data & image)

communication with Ground Control Stations in accordance with the Wireless Radio

Frequency (2.4Ghz, 5Ghz) specifications.

IPC-2221 (Generic Standard on Printed Board Design): Electronic Circuit Board

Design, Power Distribution Board Design, etc., is done according to IPC or other

applicable IC Standards for Electrical/Signal Integrity.

ROS REP (Robot Operating System Enhancement Proposals): During Software

Development, the ROS Community Naming/Package Structures (REP-103, REP-105)

will be used for Code Reusability and Modularity.

Ethical Standards:

The principles of personal data privacy (GDPR/KVKK) and ethical guidelines have been

upheld while using image processing technology during the course of this project. In

addition, it has been accepted that any images collected will only be processed for use

in search and rescue operations.

### 1.7. Work Schedule

The path to be followed in the Engineering Design and Graduation Project

process is given in Table 1.1 as a work-time graph.

In Table 1.1, the project is divided into work packages, and the work done in

each package and the time intervals in which these series must be completed are

specified. In order to avoid disruption of the work, the time period that must be

done is given in the work package. In case any problems that may arise, plans B

were considered and the risk analysis in Table 1.2 was carried out.

Table 1.1. Work-Time Table

WP No | Name and Purpose of the Work Package | Students Responsible | Time Range | Contribution to the Project
1 | Completion of the literature review and determination of unique design objectives for the project. | Berna Meltem YILDIRIM Sıla ÖZDEMİR Uygar BAŞ Ahmet Emirhan GÖKTÜRK | 01/10 /2025-12 /11 /2025 | Conducting a literature review, analyzing similar search and rescue robots, and determining system requirements.
2 | Completed 3D model of the chassis and leg structure. | Berna Meltem YILDIRIM Sıla ÖZDEMİR Uygar BAŞ Ahmet Emirhan GÖKTÜRK | 01 /10 /2025-01 /12 /2025 | Modeling the mechanical design in a CAD environment, and performing center of gravity and stability analyses.
3 | Completion of circuit schematics and component selection. | Berna Meltem YILDIRIM Sıla ÖZDEMİR Uygar BAŞ Ahmet Emirhan GÖKTÜRK | 01 /12 /2025-01 /02 /2026 | Creating the integration plan for electronic components (motor driver, sensors, microcontroller, 4G modem, GPS) and drawing circuit schematics.
4 | Completion of the mechanical prototype. | Berna Meltem YILDIRIM Sıla ÖZDEMİR Uygar BAŞ Ahmet Emirhan GÖKTÜRK | 01 /12 /2025-01 /02 /2026 | Manufacturing mechanical parts via 3D printing and assembling the robot chassis.
5 | Determination of PID parameters and observation of stable motion in simulations. | Berna Meltem YILDIRIM Sıla ÖZDEMİR Uygar BAŞ Ahmet Emirhan GÖKTÜRK | 01 /01 /2026-01 /04 /2026 | Developing the PID-based balance control algorithm and conducting simulation tests.
6 | Achieving simultaneous processing of sensor data. | Berna Meltem YILDIRIM Sıla ÖZDEMİR Uygar BAŞ Ahmet Emirhan GÖKTÜRK | 01 /03 /2026-01 /05 /2026 | Integration of sensor systems (IMU, LiDAR, camera, microphone) and performing image processing tests on the Jetson Nano.
7 | Establishment of the robot's basic locomotion (movement) capabilities. | Berna Meltem YILDIRIM Sıla ÖZDEMİR Uygar BAŞ Ahmet Emirhan GÖKTÜRK | 01 /02 /2026-01 /05 /2026 | Setup of the embedded system, software integration, and conducting locomotion (walking) tests.
8 | Ensuring low-latency (lag-free) data transmission. | Berna Meltem YILDIRIM Sıla ÖZDEMİR Uygar BAŞ Ahmet Emirhan GÖKTÜRK | 01 /03 /2026-01 /05 /2026 | Data transmission tests via 4G modem and GPS, and optimization of wireless communication.

Table 1.1. Work-Time Table (Continuing)

WP No | Name and Purpose of the Work Package | Responsible Students | Time Range | Contribution to the Project
9 | Stable operation of the robot in semi-autonomous and autonomous modes. | Berna Meltem YILDIRIM Sıla ÖZDEMİR Uygar BAŞ Ahmet Emirhan GÖKTÜRK | 01 /04 /2026-01 /05 /2026 | System testing: stability, sound detection, environmental mapping, and verification of autonomous movement.
10 | Completion of the final report and prototype presentation. | Berna Meltem YILDIRIM Sıla ÖZDEMİR Uygar BAŞ Ahmet Emirhan GÖKTÜRK | 01 /04 /2026-31 /05 /2026 | Preparing the final report, evaluating project outputs, and preparing for the presentation.

### 1.8. Risc Analysis

Table 1.2. Risc analysis and plan B

WP No | Contribution to the Project | Risc Analysis
1 | Instability in walking (locomotion) due to weight imbalance in the mechanical design. | PID control parameters will be retuned; mass distribution will be optimized through simulations, and the leg design will be updated. If necessary, the balance sensor (IMU) calibration will be repeated.
2 | Delays in the procurement of electronic components (motor drivers, sensors, 4G modems, etc.). | Components with identical technical specifications will be sourced from alternative local or online suppliers. Equivalent parts will be used for temporary testing when necessary.
3 | Occurrence of data synchronization problems between the Jetson Nano and Raspberry Pi during software integration. | Data transmission speed will be reduced to lower the processing load, and communication protocols (UART/I2C) will be reconfigured. If necessary, a data buffer will be added to prevent synchronization latency.

Table 1.3. Risc analysis and plan B (continuing)

WP No | Contribution to the Project | Risc Analysis
4 | Interruption of the 4G modem connection or signal attenuation in a disaster environment. | In case of connection loss, the robot will temporarily store data in local memory and transmit it once the connection is re-established. Alternatively, short-range backup communication will be provided via Wi-Fi or LoRa modules.
5 | Power insufficiency or battery failure during prototype testing. | A lithium battery protection circuit will be used, and operations will be supported by an external power supply during the testing process. The battery level will be continuously monitored by the software.

### 1.9. Organization of Work packages

For the project to progress in a planned and timely manner, a different person was

designated as the leader in each work package respectively. Each student carried out the

work package with discipline. Table 1.3 shows the work packages that each student led

and the number of work packages they were involved in.

Table 1.3 Distribution of Work Package

Work Package Leader | Leding Work Package | Number of Work Packages
Sıla ÖZDEMİR | 1,5,9 | 10
Uygar BAŞ | 2,6,10 | 10
Ahmet Emirhan GÖKTÜRK | 3,7 | 10

Berna Meltem

YILDIRIM

4,8 | 10

### 2. THEORETICAL BACKGROUND

### 2.1. General Information

As designing our quadruped robot prototype, we knew that its main goal was to

navigate complex terrain. A Jetson Nano, Raspberry Pi 5, an Inertial Measurement Unit

(IMU), DepthAI OAK camera, and a battery form the backbone of this robot. For the

robot’s skeleton, ABS filament was used to ensure a lightweight structure while

maintaining sufficient mechanical strength, allowing the robot to perform demanding

physical tasks without sacrificing agility. Coming heading through tight spaces, rough

terrain and uneven surfaces are no problem for the robot thanks to its carefully

developed balance and movement algorithms.

The control interface that we’re building is basically user-friendly and puts the

focus on the person operating the robot, providing a crystal-clear view of the robot’s

condition and the environment it’s operating in. We’re also working on a real-time

planning and monitoring system that lets operators monitor the progress of the robot

and stay one step ahead of the game.

The robot’s movement is achieved through coordinated control of its leg and

shoulder joints, while environmental interaction and balance are maintained using

sensor feedback.

### 2.2. Quadruped Robots and Robot Dynamics

Quadruped robots are characterized by their ability to maintain stability and

mobility through coordinated leg movements. The motion of the robot is defined by the

equations of motion governing the relationship between joint torques, link masses, and

resulting accelerations. In this study, simplified dynamic models are considered to

ensure stable and computationally efficient locomotion.

### 2.3. Kinematic Modeling of Robot Legs

Each robot leg is modeled as a serial kinematic chain. Forward kinematics is used to calculate the foot position based on joint angles, while inverse kinematics determines the required joint angles for a desired foot trajectory. Only the final kinematic relationships used in the control algorithm are presented in this section.

Figure 2.3. Calculation.

### 2.4. Robot Drive and Motors (Servo Motors)

The physical implementation of the robot’s motion control system was executed using a Raspberry Pi 5 as the primary processing unit, interfaced with a PCA9685 16-channel 12-bit PWM driver. The robot is actuated using high-torque metal-gear servo motors, which were specifically selected for their mechanical durability and high positional accuracy under load. The operation of these actuators is governed by Pulse-Width Modulation (PWM), where a mathematical relationship between the signal's duty cycle and the joint's angular position serves as the foundation for the motion control algorithms.

As illustrated in the connection diagram provided in this section, the hardware architecture utilizes the I2C communication protocol via the SDA and SCL pins of the Raspberry Pi 5. The integration of the PCA9685 driver is a critical design choice, as it offloads the PWM generation from the main CPU, providing a high resolution of 4096 steps for precise positioning.

Furthermore, to ensure system stability and comply with electrical safety standards, the power distribution for the servo motors is separated from the logic power of the microprocessor. An external power source is connected directly to the PCA9685 terminal blocks; this configuration prevents voltage drops and protects the Raspberry Pi from potential electrical noise or overcurrent generated by the motors during high-torque maneuvers. This integrated approach ensures a robust interface between the software-defined motion commands and the physical movement of the robot joints.

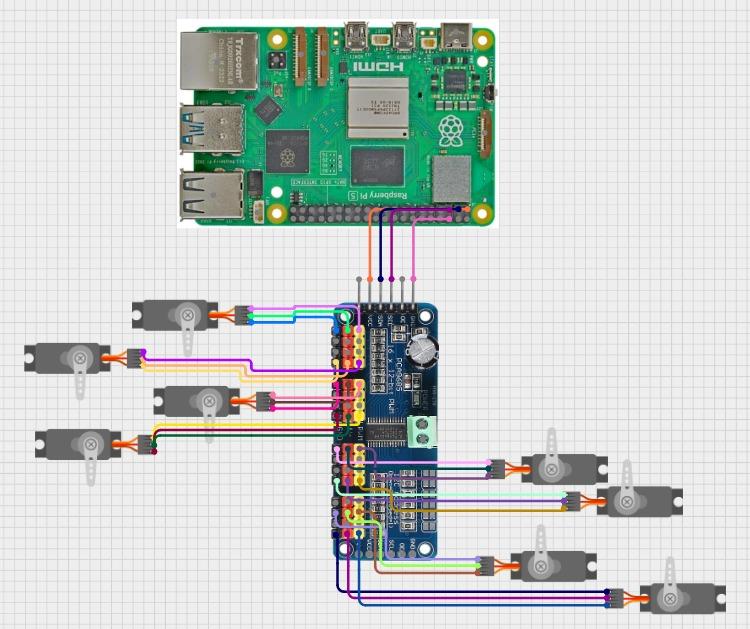
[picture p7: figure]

Figure 2.4. Servo Motors and Raspberry Pi 5.

### 2.5. Sensors and Jetson Nano’s Feedback Systems

Data integrity and low latency are ensured by the integration of sensors according

to specific industrial communication standards.

I2C Protocol (IMU Interfacing): The IMU - MPU-9250/6050 - is interfaced through

the I2C protocol, using SDA/SCL lines. This protocol enables the processor to read the

9-axis motion data of an accelerometer, gyroscope, and magnetometer with a shared

two-wire bus.

UART/Serial Communication (Lidar and GPS): The Lidar sensor provides high-

frequency data, while the GPS module provides information used for positioning, both

sent over Universal Asynchronous Receiver-Transmitter protocols. In the system

diagram, converters from USB to TTL were used as a means of bridging these sensors

with the USB ports on the Jetson, ensuring that serial data can be stably transmitted at

high baud rates.

Camera Interface: MIPI CSI The Raspberry Pi Camera Module interfaces through the Camera Serial Interface (CSI), providing a direct link to the Image Signal Processor (ISP) within the Jetson module, thereby minimizing CPU overhead during high-definition video capture.

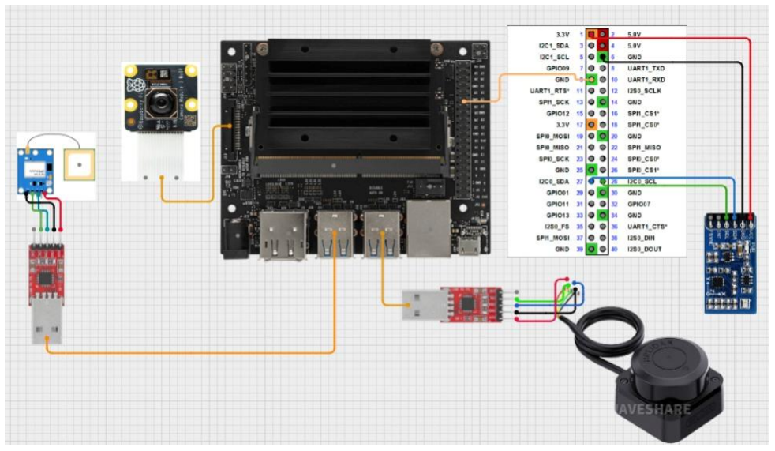
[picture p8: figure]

Figure 2.5. Jetson Nano and Sensors

### 2.6. Theory of Perception and Localization

Autonomous movement involves the simultaneous processing of both local and global coordinates.

Lidar Theory: The Lidar sensor makes use of the time-of-flight principles, emitting laser pulses and measuring the reflection time to estimate distances, thus returning a 2D point cloud of data for obstacle avoidance.

GPS Localization: The GPS module employs trilateration of satellite signals, yielding global latitude and longitude coordinates, which are necessary for long-range navigation.

### 2.7. Wired–Wireless Communication System

Wired and wireless communication methods are used in the proposed quadrupedal robot system to ensure reliable data exchange between the processing units, peripheral devices, and user interface. The communication architecture segregates high-bandwidth data transmission from low-level control communication for better stability and performance of the overall system.

Wired communication allows transmitting data over short distances with high reliability between the onboard components. As can be seen in the system connection diagram, Jetson Nano communicates with peripheral modules through USB and serial interfaces.

The Jetson Nano uses a USB interface to connect to the external communication module. The connection allows for two-way traffic of data between modules using serial communication principles. Serial communication permits structured packets of data to be transmitted sequentially, ensuring low latency and deterministic behavior for data related to control.
The general model for serial transmission of data may be represented as:

Encoder → Serial Channel → Decoder → Data → Rx

Where transmitted data is encoded into serial frames and reconstructed on the receiving side.
Wired connections are used within the robot due to their immunity against electromagnetic interference and predictable timing characteristics.

### 2.8. Wireless Data Communications

Remote monitoring and multi-machine communication are enabled by high-speed wireless protocols. The system uses a TP-Link Archer T4U dual-band USB adapter.

Communication Standard: The module utilizes the IEEE 802.11ac (Wi-Fi 5) standard, necessary to transmit high-bandwidth data such as real-time video feeds and Lidar point clouds.

Dual-Band: Operating on both 2.4 GHz and 5 GHz frequencies, the system minimizes interference. The 5 GHz band is exclusively used for low-latency control commands and high-speed data throughput.

Network Integration: In the system diagram, the Jetson is connected with the local network using a router, which enables wireless teleoperation and remote debugging from a secondary workstation.

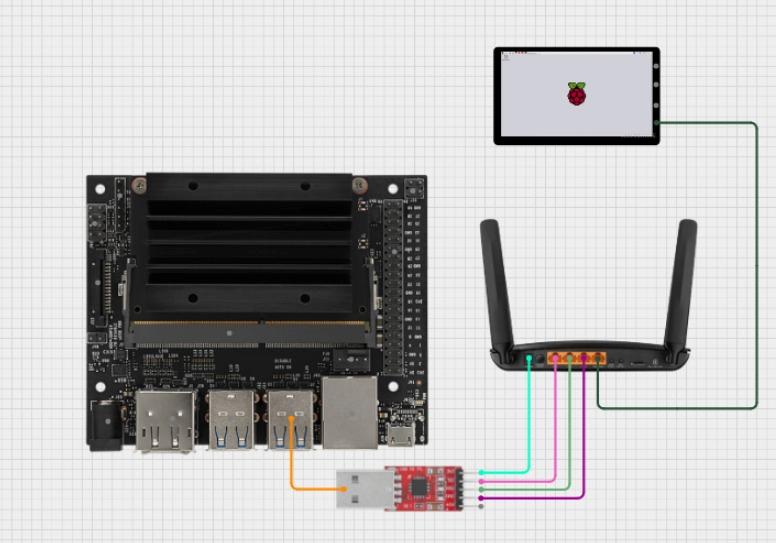
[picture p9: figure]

Figure 2.8.Wi-fi Modul and Jetson Nano

### 2.9. Microprocessors and Distributed Computing Architecture

The multi-processor approach is used in system architecture to balance highly

computationally intensive tasks with peripheral management. The main processing hub

is an NVIDIA Jetson module interfaced with a Raspberry Pi 5 for creating a distributed

computing environment.

NVIDIA Jetson (Master Unit): The module provides GPU-accelerated computing;

this is employed for heavy tasks of real-time Lidar data processing, image recognition

via the Raspberry Pi Camera Module 3 NoIR, and autonomous path planning.

The Raspberry Pi 5 is an integrated secondary unit that aids in general purpose

computing, including the ability to add more I/O flexibility in sensor management.

Inter-Processor Communication (UART): The system wiring diagrams show that

Jetson and Raspberry Pi 5 are in sync through a UART link. This connection uses Pins

8 and 10 for TXD and RXD, respectively, and Pin 39 for GND in the header of Jetson

to establish serial data communication between both platforms for low-latency

command transmission.

### 2.10. Control Methods

A hierarchical control architecture was implemented to manage the complex

movements of the quadruped robot while maintaining balance. The core of this system is

based on Inverse Kinematics calculations. In this model, it calculates the required joint

angles or each leg to move the robot's body to a specific coordinate or execute a step.

Joint Control and Precision: The calculated values of angles are sent across the I2C

bus to the PCA9685 PWM driver. The driver transforms the data into PWM signals with

a resolution of 12-bit, which is processed by the servo motors in order to achieve the

desired positions.

Dynamic Stability: The acceleration and gyroscope data from the IMU sensor are

processed continuously during locomotion to prevent the robot from tipping over. If the

tilt about the pitch/roll axes of the robot exceeds its preset limits, the real-time update in

leg lengths by the control algorithm aims to keep the center of mass within the support

polygon.

### 2.11. Human-Machine Interaction

The module will allow for operational flexibility through remote monitoring and

command transmissions via a wireless interface. This interaction layer required high-

bandwidth hardware to be selected in order to provide continuous and smooth data

exchange.

Wireless Communication Infrastructure: The data transmission on the robot is

supported by the TP-Link Archer T4U Wi-Fi adapter, according to the IEEE 802.11ac

standard. Choosing the 5 GHz band enables low-latency control commands to get through

without the signal interference common in the 2.4 GHz spectrum.

Telemetry and Visual Feedback: The operator will have the ability, on a remote

terminal, to view in real-time video from the Raspberry Pi Camera Module 3 NoIR and live occupancy grid maps derived from Lidar. This is so the operator can visually observe

the environmental perception of the robot and take any necessary intervention in its

navigation process.

### 2.12. Intelligent Systems

The "intelligence" of the robot is defined by its ability to perceive the environment

around it and make autonomous decisions. This capability is realized through the high

computing power of the NVIDIA Jetson platform combined with sensor fusion

techniques.

SLAM and Autonomous Navigation: The robot performs a SLAM by fusing distance

data from the RPLidar sensor with the orientation data from IMU. In doing so, the robot

builds a map of an unknown environment while at the same time calculating its own

coordinates in that map.

Obstacle Detection and Path Planning: The GPU cores in the Jetson module process

the Lidar point cloud to identify obstacles that lie in the path of the robot. If an obstacle

is found, the system automatically recalculates the trajectory toward the target GPS

coordinates by the safest possible path. This level of autonomy enables the robot to

perform missions in complex terrains without continuous human intervention.

### 2.13. Power Management and Energy Distribution System

The reliability of a quadruped robot depends largely on its power management

system, since it needs to provide stable voltage to sensitive electronics while supplying

high current for multiple servo motors during locomotion.

Energy Source (4S LiPo Battery): A 14.8V 4S LiPo battery with an 8000mAh

capacity was chosen as the prime source of energy. In mobile robotics, LiPo batteries are

preferred due to their high energy-to-weight ratio and the high discharge rates needed for

the sudden torque requirements of the robot's legs. The capacity of 8000mAh will ensure

extended mission times of the system dealing with the combined power draw contributed

by Jetson, Raspberry Pi 5, and the actuation layer.

Voltage Regulation (Buck Converter): Since the logic units (Jetson and RPi 5) and

the servo motors operate at lower voltage levels (typically 5V to 7.4V) than the battery's

nominal 14.8V, a high-efficiency Buck Converter (Step-Down Regulator) is utilized.

High-Current Capabilities: The converter is specified for an 8A output to

accommodate the peak current consumption. In a quadruped system with 8 or more high-

torque metal-gear servos, the simultaneous movement of multiple joints can create

significant current spikes. The capacity of 8A ensures that the voltage remains stable,

without dropping, and thus prevents "brownouts" or unexpected resets of the

microprocessors.

Safety and Efficiency: The architecture of power distribution is such that heat dissipation is minimized and electromagnetic interference is minimal. The stepping down of voltages closer to the load ensures high efficiency, hence making sure that maximum energy is directed toward the movement and processing tasks within the robot.

### 3. DESIGN

### 3.1. General Information

This section explains the engineering design of the proposed quadruped search and

rescue robot developed for operation in disaster areas. The design process is based on

mechanical, electrical, and software engineering principles, and aims to create a robust,

mobile, and energy-efficient robotic platform capable of navigating uneven terrain such

as rubble, debris, and collapsed structures.

A quadruped configuration was selected because of its superior performance

(greater stability than wheeled or tracked systems) and adaptability to different surfaces.

A quadrupedal robot design draws on existing quadrupedal robot systems as well as an

existing open-source reference, but the overall geometry has been modified to fit the

requirements of a disaster relief scenario; the dimensions (based on existing designs),

materials (based on current technology), actuator placements (based on user

specifications), and system integration (based on user requirements) have all been

redesigned.

During the design phase, key engineering calculations are carried out to support

critical decisions such as:

- Number and placement of servo motors
- Load distribution on each leg
- Required torque for joint actuation
- Power consumption and battery capacity
- Structural strength of 3D-printed components
- Control and communication architecture

Engineering of mechanical components is conducted through the use of

Computer Aided Design (CAD) software. Technical drawings will be created; these will

include the mechanical component with full numerical dimensioning, as well as the

project name, preparation date, designer names, and academic supervision. Electrical

design and software design will be created in conjunction with the mechanical design

to ensure compatibility of the entire system.

A comprehensive compilation of component parts is compiled at the conclusion

of the design phase, along with an initial investigation into costs. Additionally, the

legal and regulatory implications regarding the implementation of robotic systems in

areas of public interest and disaster response are also conducted.

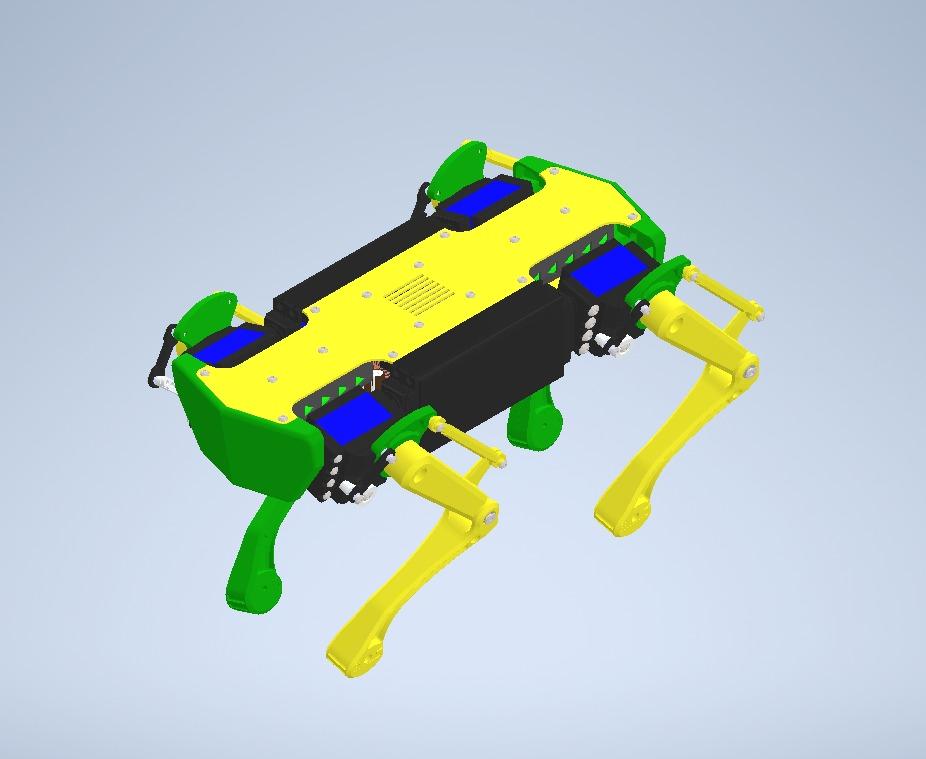
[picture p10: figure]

Figure 3.1. Overall CAD model of the quadruped robot

### 3.2. Dimensioning

The physical dimensions of the quadrupedal robots are established in accordance

with their ability to successfully navigate restricted or cluttered environments (e.g.,

earthquake debris) while providing an adequate shield for the electronic components that lie within them. The chassis of each robot is configured as a compact unit, and the

control unit, power electronic components, and battery arrangement are integrated so

that they will have a location to rest on the robot's body, and, at the same time, will be

designed with a low centre of gravity to improve the robot's (overall) stability.

The approximate body dimensions of the robot are planned as follows:

- Body Length: approximately 300 mm
- Body Width: approximately 120 mm

These dimensions allow adequate internal space for electronic components without

significantly increasing the overall mass of the system.

Each leg is designed as a multi-segment structure to enable flexible and stable

locomotion. The approximate lengths of the leg segments are:

- Coxa: approximately 40 mm
- Femur: approximately 110 mm
- Tibia: approximately 120 mm

The robot is anticipated to have an overall height from ground to top of robot

between approximately 15 cm to 20 cm. Depending on the robots posture and gait, this

height may vary somewhat. In total, the robots weight- which includes the mechanical

structure, electronics, battery, and sensors- is projected to be roughly 3,5 kg.

The dimensions listed in this section are illustrative only and serve as a reference for

the design of the robot and the development of the associated technical drawings. As

designs progress through a more detailed CAD model and integration of components

further refinements will be made to achieve final dimensional specifications.

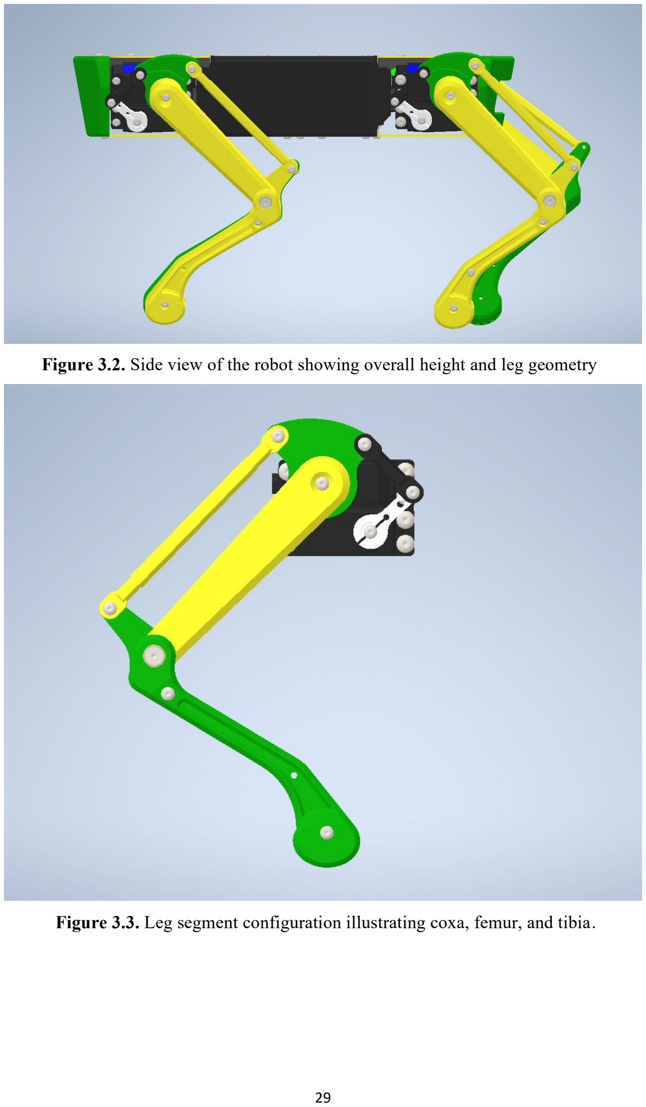
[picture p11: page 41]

Figure 3.2. Side view of the robot showing overall height and leg geometry

Figure 3.3. Leg segment configuration illustrating coxa, femur, and tibia.

### 3.3. System Components and Their Selections

The selection of system components was based on the requirements for

computations associated with autonomous navigation and artificial intelligence, in

addition to the mechanical and electrical requirements of a quadruped robotic platform

in a disaster environment. The hardware architecture of this robotic platform has been

implemented as a distributed system that separates high-level perception and decision

making from low-level motion control, which enhances reliability and permits real-time

operation.

The entire system consists of an artificial intelligence processing unit, a real-time

motion control unit, sensing modules, actuation components, and a power distribution

unit. All components were selected based on their available technical characteristics

(e.g., power consumption and compatibility with the overall architecture).

### 3.3.1. Jetson Nano Orin

NVIDIA Jetson Orin Nano was evaluated as one of the advanced control and perception units of the quadruped robot system due to its high computational performance and optimized architecture for embedded artificial intelligence applications. Its multi-core ARM processor and GPU-accelerated parallel computing capabilities provide significant advantages in real-time vision processing, deep learning–based perception, and state estimation tasks that require intensive computation.

Maintaining stable locomotion in quadruped robots requires sensor feedback data to be processed with minimal latency. Jetson Orin Nano meets this requirement through its high-bandwidth memory interfaces and hardware-accelerated compute units, enabling camera-based obstacle detection, terrain classification, SLAM applications, and proprioceptive sensor fusion to be executed on a single embedded platform.

The platform’s low power consumption provides an advantage for battery-operated mobile robotic systems. The Jetson board will be supplied through a dedicated regulated DC power line to prevent voltage fluctuations and electrical noise from affecting the computing unit. The majority of raw data processing will be executed on the Jetson, enabling Raspberry Pi 5 to focus specifically on real-time servo actuation and balance control tasks.

In conclusion, NVIDIA Jetson Orin Nano is selected as a suitable computing platform for perception, environment awareness, and advanced control functionalities required for quadruped locomotion, owing to its embedded AI computing capability, high-speed parallel processing performance, and suitability for real-time robotic applications.

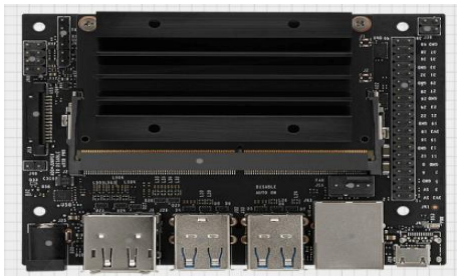
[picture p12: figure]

Figure 3.4. NVIDIA Jetson Orin Nano

### 3.3.2. Raspberry Pi 5

Raspberry Pi 5 was selected as the central processing unit of the quadruped robot

system. Owing to its compact structure, low power consumption, and high processing

capability, Raspberry Pi 5 is suitable for real-time control applications. Its advanced

multi-core ARM processor allows the execution of complex computation tasks such as

gait algorithms, balance control, sensor fusion, and image processing.

Through operating system–level multitasking, coordinated control of robot legs,

generation of motor drive signals, and processing of sensor data can be managed

efficiently. The processing capacity provided by Raspberry Pi 5 enables stable operation

even under demanding computational loads required for quadruped locomotion.

The power requirement of 5 V – 5 A is supplied through an independent regulated

power line separated from the main battery system in order to prevent voltage

fluctuations from affecting the control electronics. In addition, active cooling modules

are integrated to keep processor temperatures within safe operating limits, preventing

thermal instability during intensive workloads.

In conclusion, Raspberry Pi 5 is considered an appropriate central controller for the

quadruped robot system due to its computing performance, expandability, and

suitability for real-time robotic control tasks.

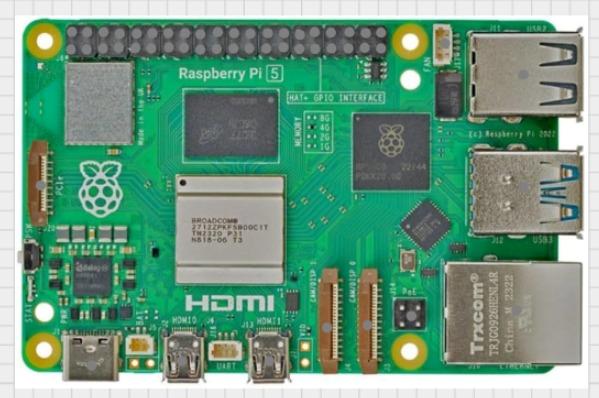
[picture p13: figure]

Figure 3.5. Rasperry Pi 5

### 3.3.3. PCA9685 16-Channel PWM Servo Driver

The PCA9685 16-channel PWM driver module is selected as the servo control

interface for the quadruped robot system. Quadruped locomotion requires simultaneous

and synchronized actuation of multiple joints; therefore, using a dedicated PWM

generator reduces timing uncertainty and prevents excessive workload on the main

processor. The PCA9685 includes a 12-bit resolution hardware PWM controller which

allows precise control of angular position and motion trajectory for each servo motor.

The module communicates with the main processing unit over the I²C interface,

enabling multiple PCA9685 boards to be addressed and expanded on the same

communication line if additional servos are required. This modular architecture

supports scalable actuation, especially in biped/quadruped systems where multiple

degrees of freedom must be coordinated in real time. The hardware PWM generation of

the PCA9685 eliminates jitter associated with software-based PWM signaling and

improves stability in closed-loop control applications.

To supply the instantaneous current demanded by multiple servos during dynamic

motion phases, an external power line is used for servo power input rather than drawing

current from the microcontroller supply. This prevents voltage drops and electrical

noise from propagating into the control electronics. The PWM frequency can be

configured to match servo specifications and torque response characteristics required

for quadruped gait execution.

Based on its multi-channel capability, stable hardware timing, low-latency control

characteristics, and compatibility with Raspberry Pi 5 and NVIDIA Jetson platforms, the PCA9685 module is determined to be an appropriate servo driver solution for

coordinated leg actuation in the quadruped robotic system.

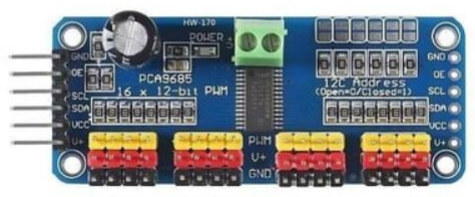
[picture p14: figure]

Figure 3.6. PCA9685 16-Channel PWM Servo Driver

### 3.3.4. The Arducam 2.3 MP AR0234 Global Shutter Camera

The Arducam 2.3 MP AR0234 global shutter camera module is selected as one of

the primary vision sensors for the quadruped robot system. The AR0234 sensor utilizes

a global shutter pixel architecture, which enables all pixels in the imaging array to

capture light simultaneously. This feature eliminates the rolling-shutter distortions

commonly encountered when imaging fast-moving objects or when the camera

undergoes rapid motion, both of which are typical conditions for mobile quadruped

robots.

With a 2.3-megapixel resolution and a 90° field of view, the camera provides

sufficient pixel density and coverage for real-time obstacle detection, terrain

classification, and visual odometry applications. The ability to capture low-latency,

distortion-free frames is essential for maintaining locomotion stability on uneven

ground and for enabling perception-guided motion planning.

The compact structure and flexible ribbon cable interface allow seamless

integration with embedded compute platforms such as Raspberry Pi 5 or NVIDIA Jetson

Orin Nano. The sensor outputs digital video streams compatible with common high-

speed interfaces used in embedded computer vision applications, ensuring deterministic

data transfer and reducing synchronization uncertainty in time-critical feedback loops.

By supplying the compute unit with reliable visual information, the AR0234

module plays a critical role in perception, state estimation, and environment awareness.

In combination with inertial and proprioceptive sensors, this camera enables robust

sensor fusion for autonomous navigation and stable quadruped locomotion.

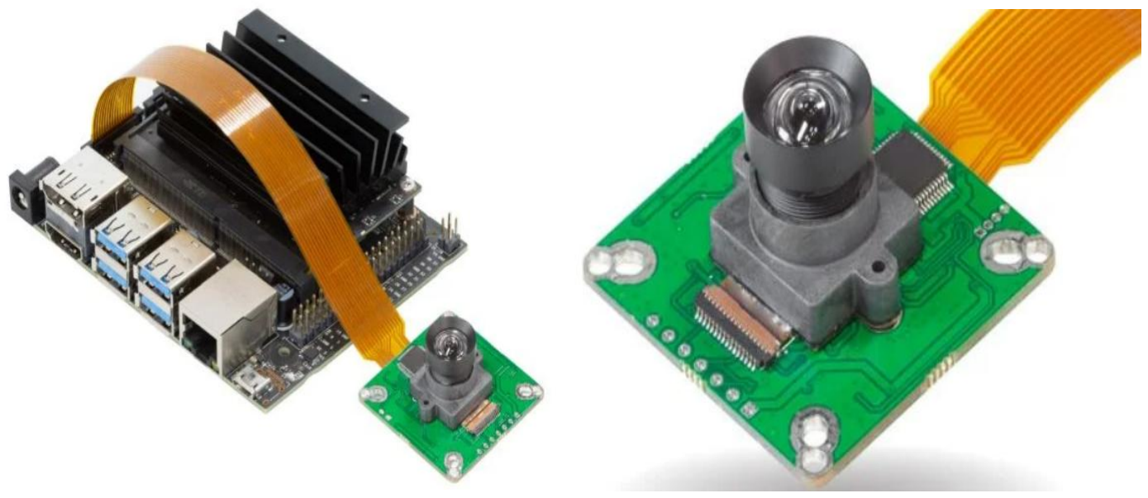
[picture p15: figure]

Figure 3.7. The Arducam 2.3 MP AR0234 Global Shutter Camera

### 3.3.5. RPLIDAR A2M8 360° Lidar Sensor

The RPLIDAR A2M8 lidar unit is selected as the primary distance-sensing

subsystem of the quadruped robot platform. The sensor provides a full 360-degree scan

range with a maximum detection distance of 12 meters and a sampling frequency of up

to 8000 samples per second. These specifications satisfy the real-time perception

requirements of a dynamically moving quadruped robot operating in both indoor and

semi-structured outdoor environments.

The ability to acquire dense range data enables accurate mapping of the surrounding

terrain geometry and reliable obstacle detection during locomotion. The lightweight

mechanical structure of the unit minimizes additional mass on the robot body,

contributing to lower inertial load during rapid maneuvers and terrain transitions. Its

low power consumption makes the device suitable for battery-powered mobile robotic

platforms.

The data provided by the lidar are processed within the perception pipeline to

generate local occupancy maps and terrain height estimations. These representations are

essential inputs for gait stability algorithms and motion planning routines. The angular

resolution and rotational scanning mechanism allow the robot to detect discontinuities

in the walking surface and adapt its step trajectory to maintain balance in real time.

The sensor communicates with the main processor through a UART or USB

interface and provides time-stamped distance measurements suitable for synchronized

sensor fusion with IMU and camera outputs. The RPLIDAR A2M8 has full ROS

support, enabling rapid integration into higher-level control architectures.

Based on its mechanical robustness, cost efficiency, adequate scanning range, and

compatibility with embedded robotic control frameworks, the RPLIDAR A2M8 is

considered an appropriate and effective lidar sensor solution for the quadruped robotic

platform.

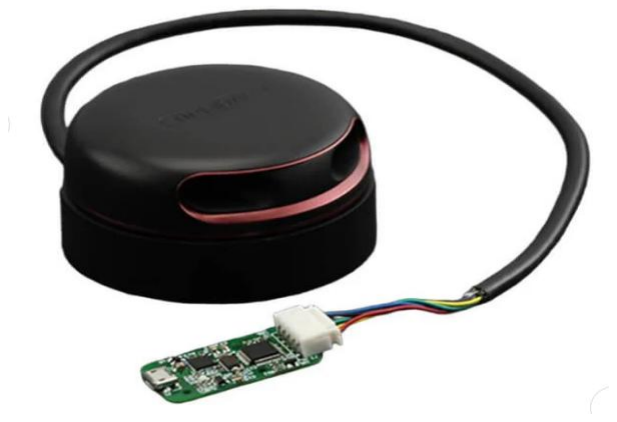
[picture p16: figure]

Figure 3.8. RPLIDAR A2M8 360° Lidar Sensor

### 3.3.6. Positioning and Navigation Unit – u-blox NEO-M8N GNSS Module

The u-blox NEO-M8N GNSS receiver module is selected to support global

positioning and navigation tasks within the quadruped robot system. GNSS-based

localization enables the robot to estimate its absolute position in outdoor environments,

facilitating high-level navigation, waypoint tracking, and environment mapping. The

module supports GPS, GLONASS, and QZSS satellite constellations and delivers a

typical horizontal positioning accuracy of approximately 2.5 meters under nominal

signal conditions.

The NEO-M8N provides a position update rate of up to 10 Hz, which is sufficient

to support the locomotion and navigation speeds expected in quadruped robotic

platforms. Communication with the onboard processing unit is achieved via a UART

interface, ensuring deterministic and low-latency transmission of navigation messages.

Support for standard NMEA message formats simplifies data parsing and integration

into ROS-based robotics frameworks.

To improve satellite acquisition time and signal robustness, an external active

antenna will be employed, and optional SBAS correction capabilities may be enabled

depending on deployment conditions. The module’s compact dimensions and low

power consumption provide advantages for battery-powered mobile robotics

applications where energy efficiency and mechanical integration constraints are critical.

When combined with proprioceptive and exteroceptive sensors such as IMUs and

lidar, GNSS data contributes to multi-sensor fusion algorithms that enhance reliability in outdoor navigation. In this context, the NEO-M8N module is considered suitable as

the primary GNSS receiver for the quadruped robot platform due to its cost efficiency,

adequate positioning performance, and compatibility with embedded control

architectures.

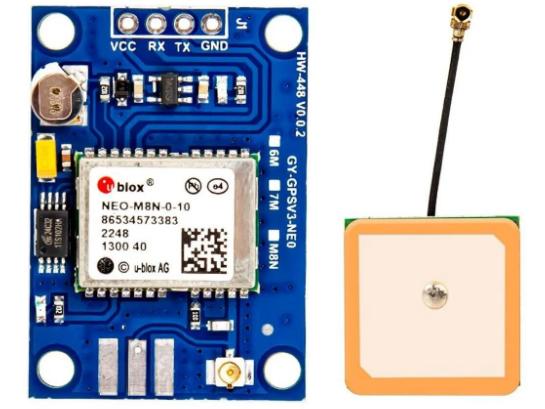
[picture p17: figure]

Figure 3.9. Positioning and Navigation Unit – u-blox NEO-M8N GNSS Module

### 3.3.7. MG996R High-Torque Servo Motor

The MG996R metal-gear servo motor is selected as one of the primary joint

actuators in the quadruped robot system. Quadruped locomotion requires high torque

levels for joint articulation, particularly during stance phases in which the load of the

robot body must be supported by individual legs. The MG996R provides a stall torque

capacity of approximately 9–11 kg·cm at 6 V supply voltage and delivers sufficient

mechanical power for hip and knee joint actuation within lightweight mobile platforms.

Internal metal gear construction increases mechanical durability and improves

resistance to repetitive impact stresses that occur during walking and trotting gait

cycles. The servo incorporates an onboard control circuit and potentiometric feedback,

enabling closed-loop angular position control through standard PWM modulation. This

property facilitates integration with the PCA9685 servo driver, allowing synchronized

multi-joint control and stable trajectory execution.

The actuator operates at nominal voltages of 4.8–7.2 V and exhibits current draw

levels that increase significantly under load conditions. For this reason, separate

regulated power delivery and current limiting protections are included in the power

subsystem to maintain system stability and prevent voltage sag during dynamic

movements. Shaft angle resolution and torque response characteristics are considered

suitable for low-to-medium precision legged locomotion tasks.

In conclusion, the MG996R servo motor is selected based on its high torque output,

mechanical robustness, integrated position feedback, and compatibility with the selected servo drive architecture, making it appropriate for joint actuation requirements

in the quadruped robotic platform.

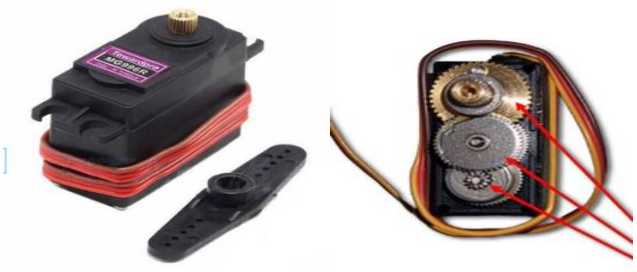
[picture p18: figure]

Figure 3.10. MG996R High-Torque Servo Motor

3.3.8. 4S 14.8 V LiPo Battery Pack (8000 mAh class)
A 4-cell (4S) 14.8-V Lithium-Polymer (LiPo) battery pack is selected as the

primary onboard energy storage unit for the quadruped robotic platform. Quadruped

locomotion imposes highly dynamic mechanical loading on leg actuators, resulting in

instantaneous current spikes during stance and lift-off phases. LiPo cell chemistry

supports high discharge rates and provides the transient current supply necessary for

stable servo torque output without excessive voltage droop.

The selected capacity class (approximately 8000 mAh) enables sufficient

operational duration for typical experimental locomotion trials, while maintaining a

reasonable mass-to-energy ratio suitable for mobile platforms in which battery weight

directly influences gait stability and actuator load. The nominal pack voltage of 14.8 V

is regulated through dedicated buck converters to supply appropriate voltage rails for

the computing units (e.g., Raspberry Pi 5 and NVIDIA Jetson Orin Nano), servo driver

circuits, and auxiliary sensors.

LiPo batteries provide high energy density but require careful management of

charge-discharge cycles to prevent thermal instability and long-term degradation. For

this purpose, over-current, under-voltage, and thermal protection mechanisms are

integrated into the battery management subsystem. Cell balancing mechanisms will be

applied during charging to prolong usable service life and ensure uniform voltage

distribution across series-connected cells.

Based on its high discharge capability, favorable mass-to-capacity characteristics,

and compatibility with the dynamic current requirements of multi-servo quadruped

actuation, the 4S 14.8-V LiPo battery pack is determined to be an appropriate energy

storage component for the proposed robotic system.

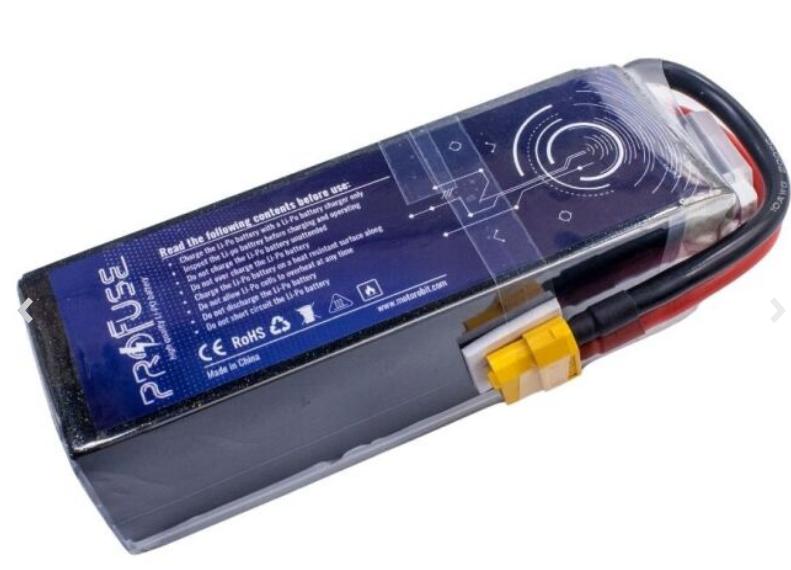
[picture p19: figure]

Figure 3.11. 4S 14.8 V LiPo Battery Pack (8000 mAh class)

3.3.9.The TP-Link Archer T4U dual-band Wi-Fi adapter

The TP-Link Archer T4U dual-band Wi-Fi adapter is selected to provide wireless communication between the quadruped robot platform and an external control or monitoring workstation. Because the communication architecture does not require cellular connectivity, the Wi-Fi interface enables a cost-efficient and infrastructure-compatible method for transmitting telemetry, sensor status, and control commands through a local wireless network.

The Archer T4U supports IEEE 802.11ac dual-band operation (2.4 GHz and 5 GHz) and connects to the onboard computing system through a USB 3.0 interface. The 5 GHz band enables higher throughput and reduced latency, which are critical for real-time communication tasks such as state updates, operator command input, and low-bandwidth video streaming. Linux driver compatibility facilitates seamless integration with the Jetson platform, allowing the network interface to be recognized as a standard wireless adapter by the operating system.

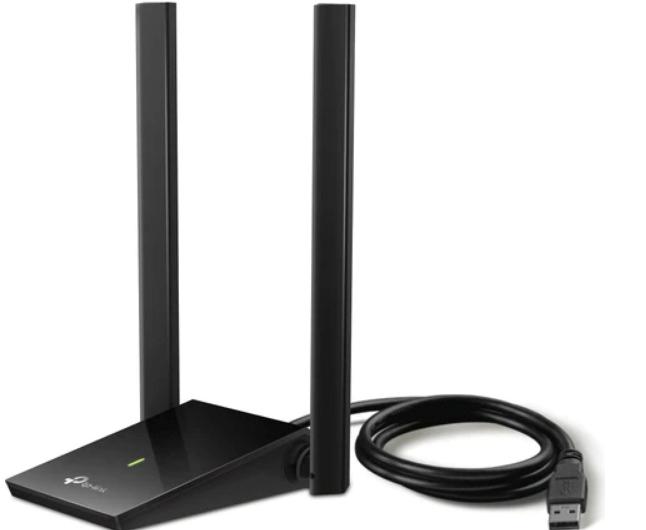
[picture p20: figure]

Figure 3.12. The TP-Link Archer T4U dual-band Wi-Fi adapter

### 3.4. Applied Methods

This section describes the engineering methods applied during the design of the

quadruped robot, including mechanical load analysis, actuator torque estimation,

kinematic modeling, power analysis, and control strategy selection. These methods are

used to guide component selection and system architecture design.

### 3.4.1. Load Distribution and Static Analysis

To estimate the mechanical load acting on each leg, the total robot weight is

assumed to be evenly distributed among four legs during static standing conditions. The

load acting on a single leg is calculated using Equation (1).

Fleg =

W
4

(1)

W is the total robot weight and Fleg is the load acting on a single leg.

For a robot mass of 3.5 kg, the force acting on each leg is calculated as given in

Equation (2).

Fleg =

3. 5 × 9. 81
4
≈ 8. 6 N | (2)

### 3.4.2. Servo Motor Torque Calculation

Servo motors are selected based on the torque required to support the robot body

and generate leg motion. The required torque for a joint is estimated using Equation

(3).
τ = F ⋅ r | (3)

Using an effective lever arm length of approximately 0.12 m, the required torque

per joint is calculated as shown in Equation (4).

τ ≈ 8. 6 × 0. 12 = 1. 03 Nm | (4)

A safety factor greater than 1.5 is considered to account for dynamic loads during

locomotion, leading to the selection of 20 kg·cm torque servo motors.

### 3.4.3. Structural Strength of 3D Printed Parts

The mechanical strength of the 3D-printed leg and body components is evaluated using

bending stress analysis. The bending stress is calculated according to Equation (5).

σ =

M × c
I

(5)

σ is bending stress,

M is bending moment,

C is the distance from the neutral axis, and

I is the area moment of inertia.

This analysis guides the selection of wall thickness, infill ratio, and filament

material to ensure sufficient strength while minimizing weight.

### 3.4.4. Kinematic Modeling and Inverse Kinematics

Leg motion is controlled using inverse kinematics to determine the joint angles

required to achieve a desired foot position. For a planar two-link leg model, the joint

angles are calculated using Equations (6) and (7).

θ2 = cos⁻1
(

x

2 + y

2 − l1

2 − l2

2
2l1l2
) | (6)

θ1 = tan⁻1

y
x

− tan⁻1

l2 sin θ2 l1 + l2 cosθ2 | (7)

where l1and l2represent the femur and tibia lengths.

### 3.4.5. Power Consumption and Battery Capacity Estimation

The total current consumption of the robot is estimated by summing the current

demands of major components as expressed in Equation (8).

Itotal = ∑Iservos + Iprocessors + Isensors | (8)

The approximate operating time of the battery is calculated using Equation (9).

T =

C

Itotal

(9)

C is the battery capacity in ampere-hours.

This estimation supports the selection of a 3S Li-Po battery to meet operational

requirements.

### 3.5. Software Used

The software architecture of the quadruped robot is developed using a layered

approach separating high-level perception from low-level motion control.

The main software tools and platforms used include:

- Ubuntu Linux running in VirtualBox for development
- ROS2 for inter-process communication and modular software design
- Gazebo for simulation and visualization
- Raspberry Pi Imager for operating system deployment

High-level tasks such as image processing and object detection are executed on the

NVIDIA Jetson Nano, while real-time control tasks including inverse kinematics and

servo control are handled by the Raspberry Pi.

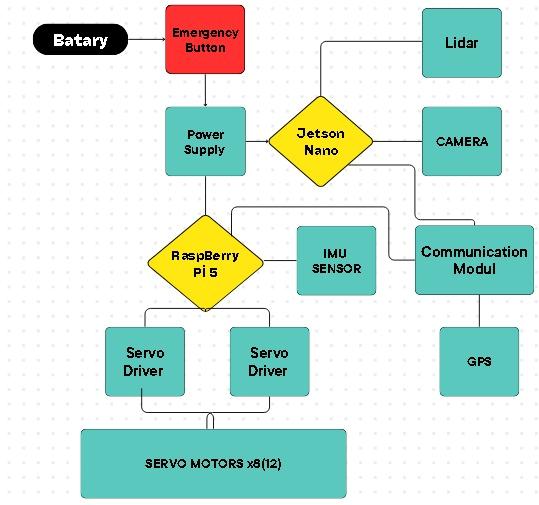
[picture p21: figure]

Figure 3.13. Software architecture and data flow diagram.

### 3.6. Component List and Economic Analysis

After the completion of the project design phase, the proposed system is planned

to be realized through the procurement and integration of the required hardware

components. Market research was conducted for all materials specified in the design

stage of the quadruped robot, and a preliminary cost calculation was performed based

on current market prices. The component list and the estimated cost analysis resulting

from this planning are presented in Table 3.1.

Table 3.1. Component List

Component Name | Purpose of use | Unit Price (TL) | Quantity | Price (TL)
Waveshare Jetson Orin NX 16GB AI Kit (WiFi) | High-level AI processing, image processing, object detection | 52,489.32 TL | 1 | 52,489.32 TL
Raspberry Pi 5 | Low-level motion control and inverse kinematics calculations | 3,015.35 TL | 1 | 3,015.35 TL
PCA9685 16-Channel I2C PWM Servo Driver | PWM signal generation for servo motors | 195.71 TL | 1 | 195.71 TL
MG996R Metal Gear Digital Servo Motor | Leg joint actuation | 172.46 TL | 8 | 1,379.68 TL
TP-Link Archer TX20U Plus | Wireless communication (WiFi) | 1,501.48 TL | 1 | 1,501.48 TL
Arducam 2.3MP AR0234 | Visual perception and camera input | 4,686 TL | 1 | 4,686 TL
A2M8 RPLIDAR 360° | Distance measurement & obstacle detection | 11,842.62 TL | 1 | 11,842.62 TL
Tinylab 3D 1.75 mm ABS Filament | Mechanical part manufacturing | 3,040.00 TL | 1 | 3,040.00 TL
TOTAL | | | | 78,150.16 TL

### 3.7. Legal Aspects

This section evaluates the potential legal and regulatory considerations related to

the development and use of the proposed quadruped search and rescue robot. Since the

robot is designed for operation in disaster and emergency environments, compliance

with relevant safety, electrical, and operational regulations is taken into account during

the design phase.

- Safety for Batteries and Electricity

The robot operates with LiPo batteries as the main power source. Because LiPo

batteries can present dangers related to overheating, short-circuiting, and damage from

impact, the design implements a means of providing voltage regulation and current

protections. The entire electrical system meets the general principles of safety for low-

voltage equipment to limit the level of danger throughout the usage of the robot.

- Mechanical Safety

Movement via removable parts, such as joints and mechanism, is part of the

structure of the machine. When in action, these mechanics can create a hazard for users

through possible injury from moving parts. To reduce this risk, cutting areas were not

included in the design of the mechanism and were positioned away from any areas

where direct access could occur. The intended environment for using this particular

piece of machinery is in emergency response situations, where trained personnel will

operate it within a controlled setting.

- Operational Use in Disaster Areas

Structurally, the system has been created to serve primarily as an aid to humanitarian

agencies conducting search and rescue missions rather than as a substitute for human

input. Furthermore, its deployment in areas affected by disasters will require the

appropriate approvals by local public administrations/authorities, as well as

governmental/emergency response organizations. The software features and attributes

of this robotic system are consistent with those used in traditional operational guidelines

established for emergency response operations.

- Data Privacy and Ethical Considerations

The robot uses camera and sensor systems to perceive its environment. Image and

sensor data collected during operation are intended solely for search and rescue

purposes. Personal data protection principles are considered, and data usage is limited to operational requirements. Any future use of the system involving data recording or

transmission would need to comply with applicable data protection regulations.

### 4. SIMULATION STUDIES

### 4.1. General Information

The design of the robotic leg mechanism is bio-inspired and follows a typical quadruped animal model defined by a skeleton. The design is comprised of two main parts: Upper Leg (Femur) and Lower Leg (Tibia).The Upper Leg is a primary support link for the chassis and also serves as a connection to both the chassis and Lower Leg (Tibia). The Tibia describes the bottom section (lower leg) of the robotic leg and provides contact with ground. The ends of these parts are referred to as end-effectors. Lastly, the physical dimensions of the parts were determined based on dimensionally accurate 3D printed replicas of both parts: "femur v2_4pcs.STL" (upper leg) and "tibia v4_R-onepiece.STL" (lower leg). The dimensions of the links (i.e. L_1 and L_2) are set to 100 mm in the simulation to match proportions of the physical prototype.

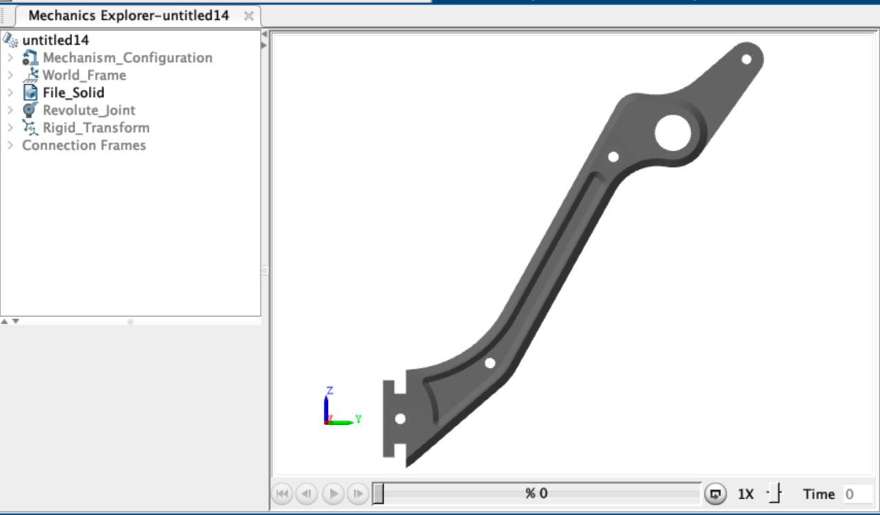
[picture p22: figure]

. | Figure 4.1. 3D Visualization of the Tibia Component

3D view of the robot’s tibia segment within the Simscape Multibody environment.

The part's center of inertia and joint orientation have been computationally verified in

the digital domain to ensure physical accuracy during simulation.

### 4.2. Simulation Software

The dynamic performance and kinematic precision of the design were evaluated using the Simscape Multibody environment in MATLAB/Simulink. In this simulation setup, there were three primary blocks: The World Frame and Solver Configuration define the global coordinate frame and the parameters for numerical integration; The Mechanism Configuration specifies the acceleration due to gravity of -9.81m/s^2, which simulates a physical environment with this force; and The Revolute Joint represents the hip and knee joints, which provide these joints with the ability to rotate about an axis of rotation. The File Solid block imports the STL geometries, with all associated mass and inertia values specified in the physics engine.

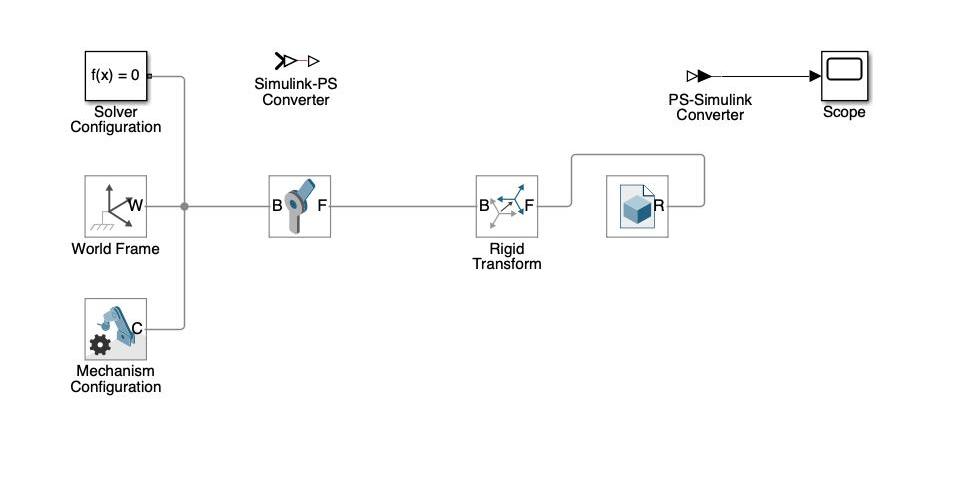
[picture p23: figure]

Figure 4.2. Simulink Block Diagram of the Robotic Leg Mechanism.

Simulink Block Diagram of the Robotic Leg Mechanism:

This diagram illustrates the integrated simulation architecture where mathematical control algorithms and physical multi-body dynamics are coupled to analyze the leg's kinematic behavior.

### 4.2. System Modeling

Inverse Kinematics (IK) is the process of calculating the required joint angles to move the foot-end to a specific target (x, y) coordinate. The model relies on the Law of Cosines to solve the geometric relationship between the links.

The the joint angle (q) is calculated by using Equation (10).

D = (x

2 + y

2 − L1

2 − L2

2)/(2 ∗ L1 ∗ L2) | (10)

q = arccos(D)

This ensures that for any reachable target point, the system generates a stable angular command for the actuator.

### 4.3. Simulation

Algorithm Implementation
In the preceding section, we implemented the mathematical model via a MATLAB function block within a Simulink environment. Using this implementation, the target Cartesian coordinates (x, y) can be converted into joint angles (q). By doing this, we can ensure that the robot properly reaches the desired touchdown points within its gait cycle.

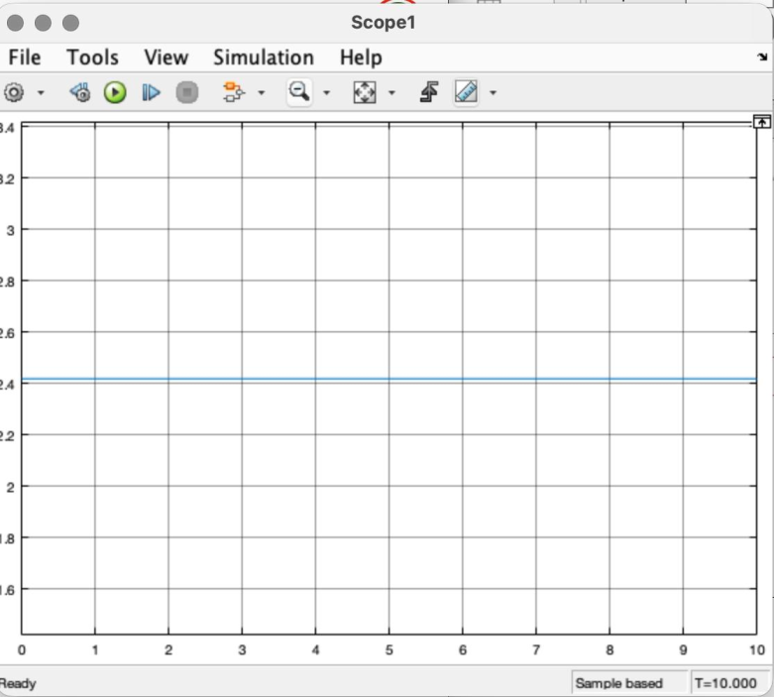
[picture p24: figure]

Figure 4.3. The MATLAB Function block that implemented the inverse kinematics algorithm can be seen in conjunction with the Scope output from constant (x,y) inputs. It was able to compute joint angles of 2.4 radians corresponding to the target point and achieve a consistent mechanical position.

### 4.4. Dynamic Testing and Trajectory Tracking

The inverse kinematics (IK) algorithm controlled the leg mechanism in response to dynamic input signals. In order to maintain the numerical stability of these signal inputs during testing, all inputs had second-order filtering applied to them prior to being input into the IK algorithm. Likewise, the Simscape engine performed automatic computation for joint torque values throughout the entire testing process resulting in successfully tracking of the targeted trajectories by the foot-end.

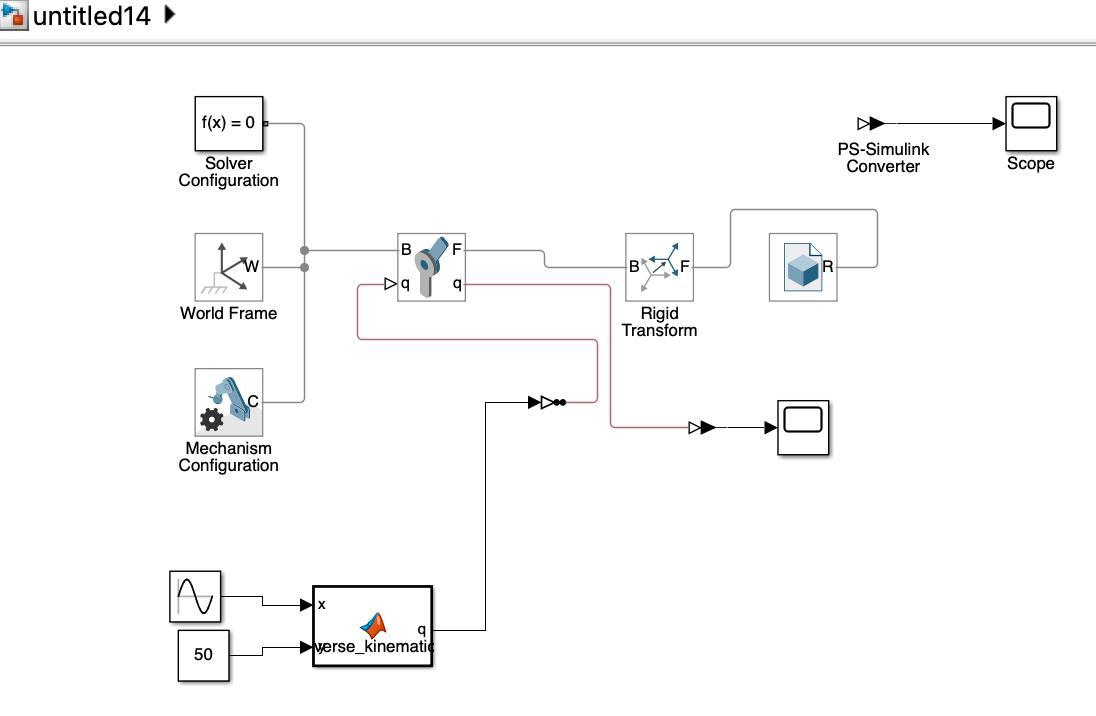
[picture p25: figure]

Figure 4.4. Dynamic Control Block Diagram shows the conceptual overview of the Dynamic Control System Architecture. The Figure depicts the process of sending the Reference Sine Wave from MATLAB Function Block (MFB) to Joint Actuator.

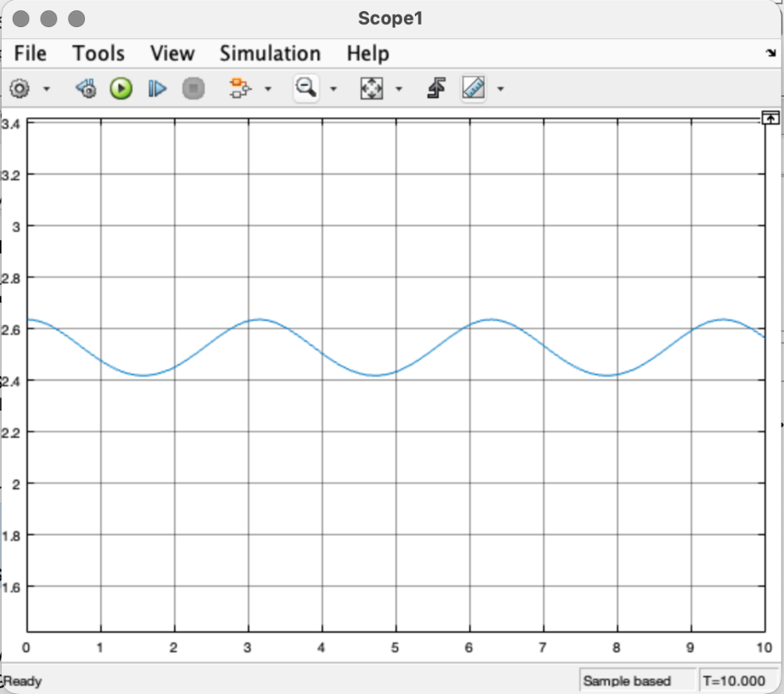
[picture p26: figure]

Figure 4.5. Dynamic Trajectory Tracking Graph shows the Trajectory Tracking and Periodic Output graph, which records a periodic (sinusoidal) output as measured with the Scope, and illustrates how well the Trajectory Tracking will perform and the periodic motion of the foot during the Gait Cycle.

### 5. RESULTS

### 5.1. General Information

The technical products, numerical information, and visual representation of results contained in this section show the success (or failure) of meeting the stated goals of the search and rescue robot project. The academic community does not accept photographs of an experiment as a valid result; rather, graphs, figures, and tables provide tangible evidence of the system achieving its goal.

The results of this study are separated main groups: simulation results provided by computer -generated models; and hardware experimental results based upon tests conducted on a prototype constructed from physical materia

### 5.2. Simulation Results

Using the Simscape Multibody environment in MATLAB/Simulink, a simulation model of a quadruped robot was created to analyze kinematic accuracy and trajectory tracking.

Inverse Kinematics (IK) Accuracy: A mathematical model based on the Law of Cosines was implemented as MATLAB Function Block to convert Cartesian coordinates into joint angles.

Target Achievement: When the algorithms were tested with constant (x,y) inputs, the algorithm calculated joint angles of 2.4 radians, allowing the robotic leg to achieve one consistent mechanical position. Trajectory Tracking: Through dynamic control tests, using a sine wave reference command to the joint actuators allowed simulating the gait cycle.

Gait Cycle Stability: The graphs derived from trajectory tracking tests illustrated the ability of the foot-end to follow periodic motion throughout the locomotion phases of stability.

### 5.3. Experimental Results

The project was physically built using a combination of high-level perception and low-level control, which was accomplished by using a hybrid processor architecture.

Actuation and Control: The Raspberry Pi 5 received PWM signals with 12-bit resolution from the PCA9685 driver, allowing the application of 12-bit PWM signals to provide 4096 steps of precise positioning of the metal gear servo motors.

Edge AI Performance: The Jetson Nano allowed for an edge-based deep learning model (YOLO) to locally execute the detection of human body shapes and "thermal signals of life" from camera feeds.

Mapping and SLAM: By combining 360-degree scanning information (from an RPLIDAR A2M8) with orientation data from the Inertial Measurement Unit (IMU), the robot built an Occupancy Grid (OG) map with accurate positional coordinates.

Environmental Perception: The use of a global shutter camera (Arducam) removed rolling shutter effects that occur when moving rapidly so that accurate visual information could be gathered for avoidance of obstacles.

Power Management: The 14.8V 8000mAh lithium polymer (LiPo) battery had enough available amps to supply power to both processor and actuation layers, thus permitting maximum search and rescue mission duration.
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

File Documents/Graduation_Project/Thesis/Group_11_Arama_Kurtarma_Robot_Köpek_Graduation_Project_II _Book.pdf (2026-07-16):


T.C.

## OSTIM TECHNICAL UNIVERSITY Faculty of Engineering

### Department of Electrical and Electronics Engineering

# Design and Implementation of a Search and Rescue Robot Dog for Disaster Areas

# Graduation Project II

### 210202023 Uygar BAŞ 210202015 Sıla ÖZDEMİR 210202009 Berna Meltem YILDIRIM 210202003 Ahmet Emirhan GÖKTÜRK

## Supervisor

## Dr. Şenol GÜLGÖNÜL

### May 2026 ANKARA

T.C.

## OSTIM TECHNICAL UNIVERSITY Faculty of Engineering

### Department of Electrical and Electronics Engineering

# Design and Implementation of a Search and Rescue Robot Dog for Disaster Areas

# Graduation Project II

### 210202023 Uygar BAŞ 210202015 Sıla ÖZDEMİR 210202009 Berna Meltem YILDIRIM 210202003 Ahmet Emirhan GÖKTÜRK

## Supervisor

## Dr. Şenol GÜLGÖNÜL

### May 2026 ANKARA

i

GRADUATION PROJECT APPROVAL FORM

The undergraduate graduation project titled “[Afet Bölgelerinde Arama Kurtarma Amaçlı Robot Köpek Tasarımı ve Uygulaması]”, prepared by [Uygar BAŞ, Sıla ÖZDEMİR, Berna Meltem YILDIRIM, Ahmet Emirhan GÖKTÜRK] under the supervision of

[ Dr. Şenol GÜLGÖNÜL] was examined and accepted as an Undergraduate Graduation Project in terms of its scope and quality.

Supervisor | : Dr. Şenol GÜLGÖNÜL
Jury member 1 | : Dr. Burak YENİPINAR
Jury member 2 | : Prof. Dr. Sinan KIVRAK
Head of the Department | : Prof. Dr. İsmail Hakkı ALTAŞ

ii

FOREWORD

This graduation project was prepared by the students of the Department of Electrical and Electronics Engineering, Faculty of Engineering, OSTIM Technical University, within the scope of Graduation Project II. The project focuses on the design and implementation of a quadruped robot dog intended for search and rescue operations in disaster areas.

We would like to take this opportunity to express our thanks to Asst. Prof. Dr. Senol GULGONUL, our project supervisor and mentor, for the valuable support and guidance that he provided us during the development of our final project. His knowledge and encouragement were critical to successfully completing our graduation project.

We would also like to thank Professor Dr. Ismail Hakkı ALTAS, Head of the Electrical and Electronics Engineering Department, for providing us with an outstanding academic environment that enabled us to successfully complete our graduation project.

Finally, we would like to express our heartfelt appreciation to all our families for their continuous support, patience, and encouragement throughout our academic journey, including the completion of our final project.

May 2026

Uygar BAŞ
Sıla ÖZDEMİR
Berna Meltem YILDIRIM
Ahmet Emirhan GÖKTÜRK

iii

CONTENTS

1.1.1. Global and Regional Impacts of Natural Disasters and the Need for Search
1.1.2. Evolution of Mobile Robotic Systems: Transition from Wheeled to Legged

iv

v

vi
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

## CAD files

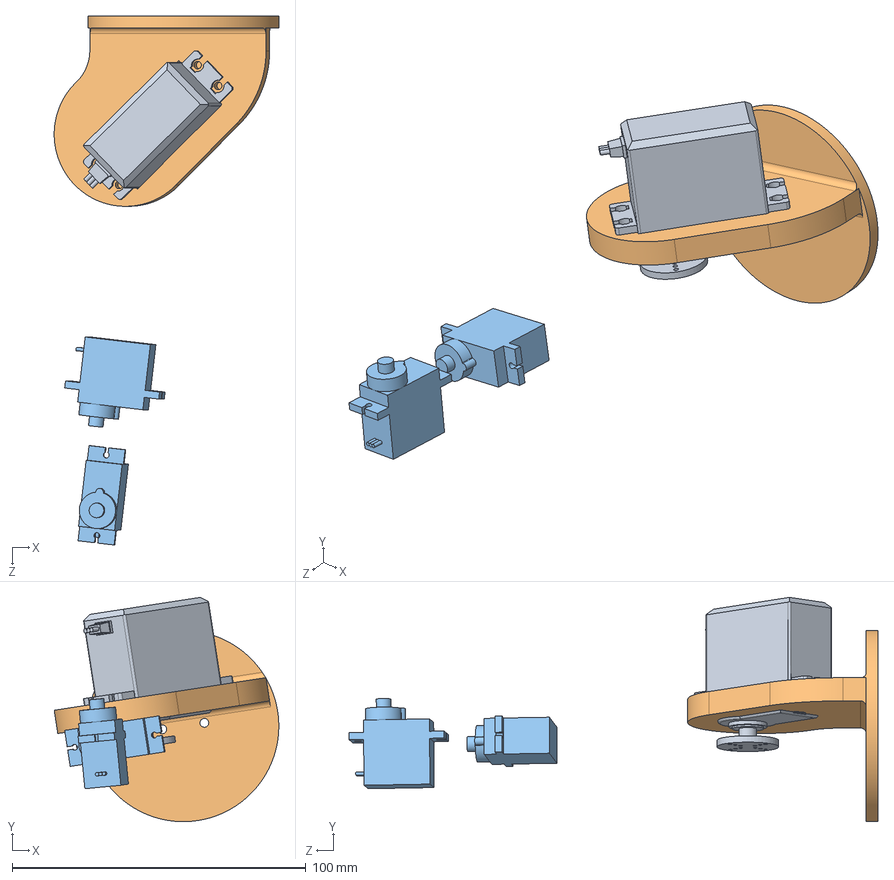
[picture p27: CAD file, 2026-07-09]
CAD/SolidWorks/Assemblies/ROBOT_KOL.SLDASM
76.4 x 76.3 x 180.0 mm
Servo Motor Micro 9g x 2
Waist
Servo Motor MG996R

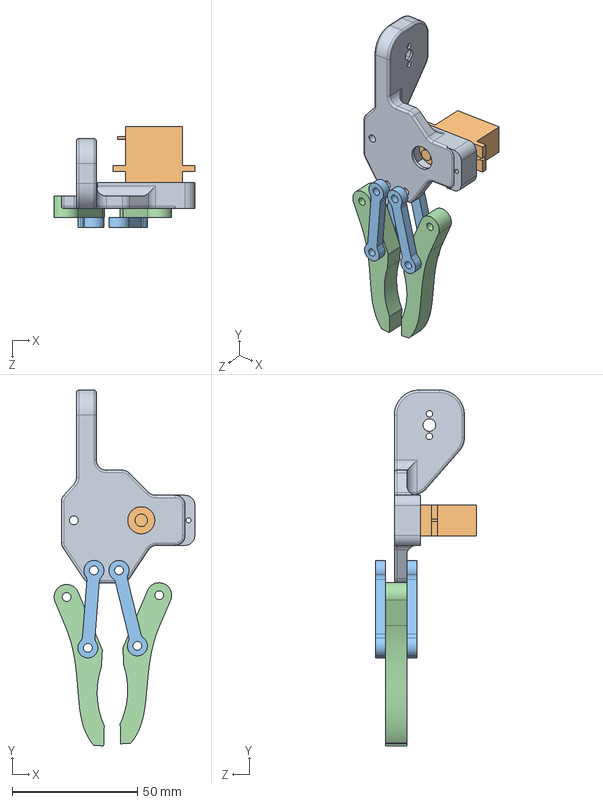
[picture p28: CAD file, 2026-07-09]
CAD/SolidWorks/Assemblies/Gripper assembly.SLDASM
56.2 x 142.1 x 40.3 mm
Gripper x 2
Gripper Link x 4
Servo Motor Micro 9g
Robot Gripper Design

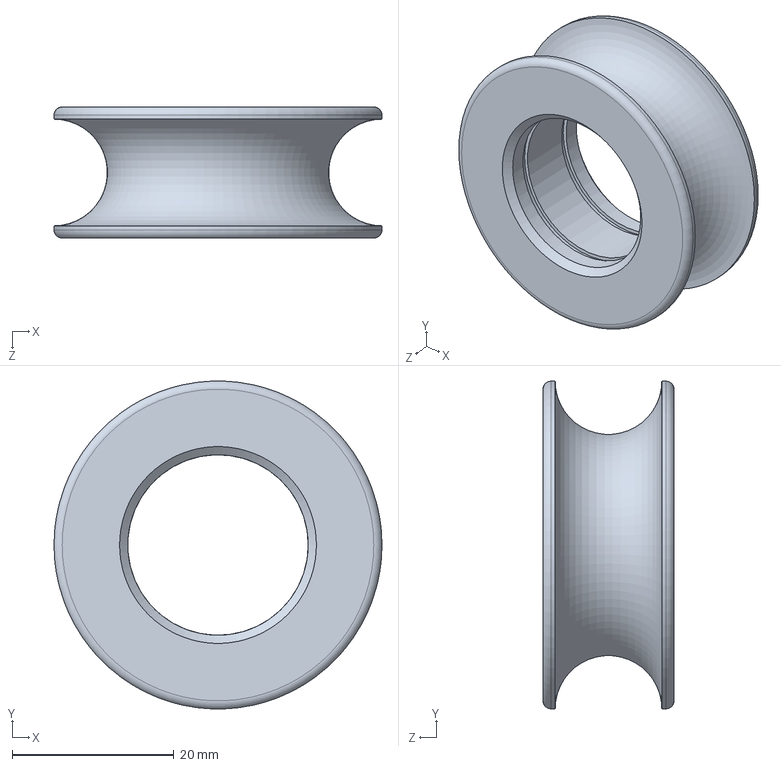
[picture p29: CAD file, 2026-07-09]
CAD/SolidWorks/Parts/wiel.SLDPRT
40.5 x 40.5 x 16.2 mm

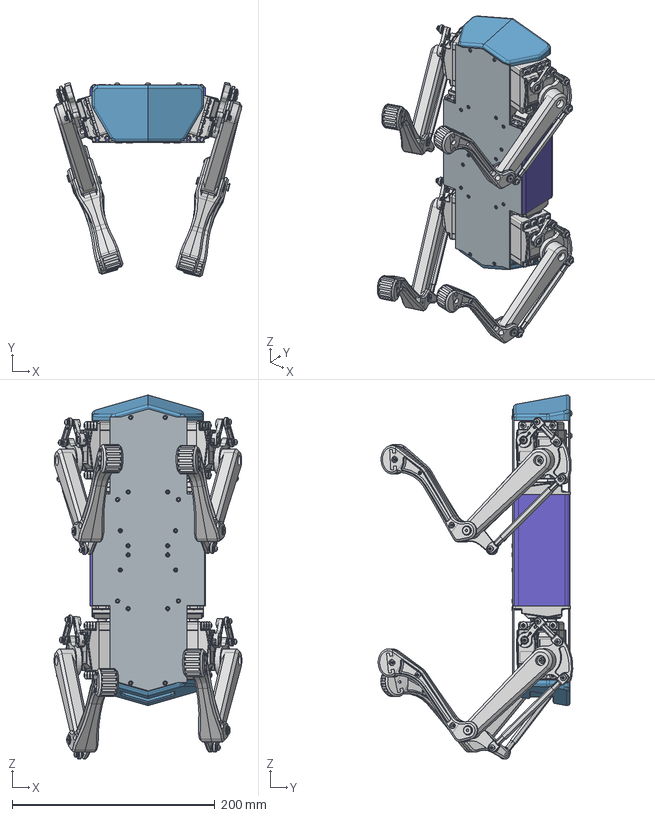
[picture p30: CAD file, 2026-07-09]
CAD/STEP/BORUTAY_Kolsuz.step
185.2 x 192.0 x 358.9 mm
gövde1-V2
spt5435LV x 12
servo arm round x 4
femur v2 x 4
tibia v4 x 2
servo arm mod-v2 x 2
2servo holder2 x 2
spacer-for100mm x 4
rodend 5mmPlastic x 16
rodend 5mmBall x 16
servo arm 1 x 4
2servo holder3 x 2
Servo Mount - Arm Metal Standard_Dfaut x 4
socket button head cap screw_am_B18.3.4M - 3 x 0.5 x 12 SBHCS --N x 59
684z bearing x 8
socket countersunk head screw_am_B18.3.5M - 4 x 0.7 x 12 Socket FCHS -- 12N x 8
mirror-tibia v4 x 2
Aynalama2servo holder3 x 2
Aynalama2servo holder2 x 2
Aynalamaservo arm mod-v2 x 2
socket button head cap screw_am_B18.3.4M - 4 x 0.7 x 8 SBHCS --N x 24
socket head cap screw_am_B18.3.1M - 3 x 0.5 x 20 Hex SHCS -- 20NHX
socket button head cap screw_am_B18.3.4M - 3 x 0.5 x 6 SBHCS --N
socket button head cap screw_am_B18.3.4M - 3 x 0.5 x 10 SBHCS --N x 3
ön1-V2
üst sac
ARKA1-V2-SWITCH
Bileşen43
gövde2-V2

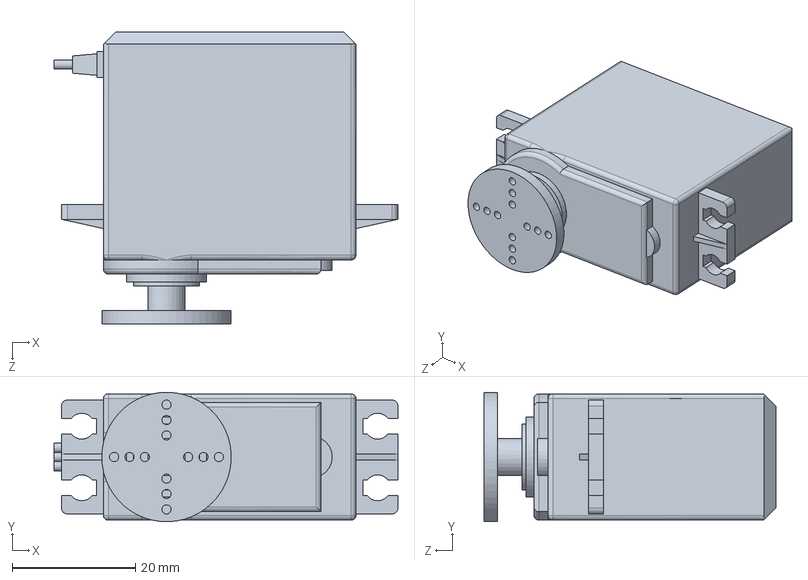
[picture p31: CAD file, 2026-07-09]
CAD/SolidWorks/Parts/Servo Motor MG996R.SLDPRT
55.8 x 21.0 x 47.4 mm

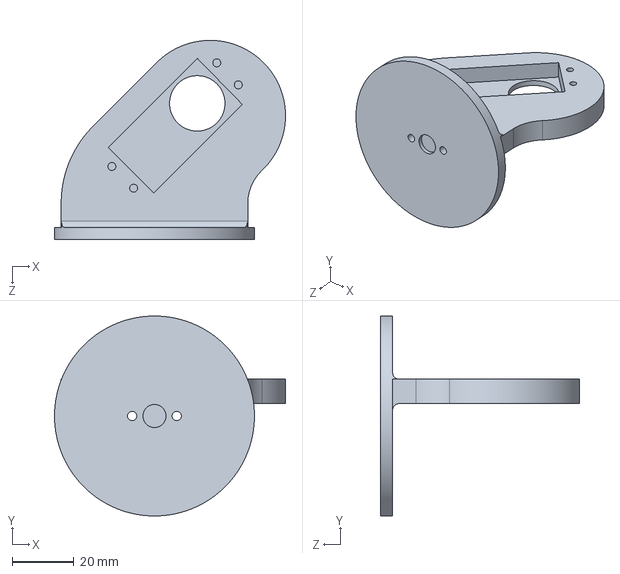
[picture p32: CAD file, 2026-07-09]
CAD/SolidWorks/Parts/Waist.SLDPRT
75.1 x 65.0 x 64.7 mm

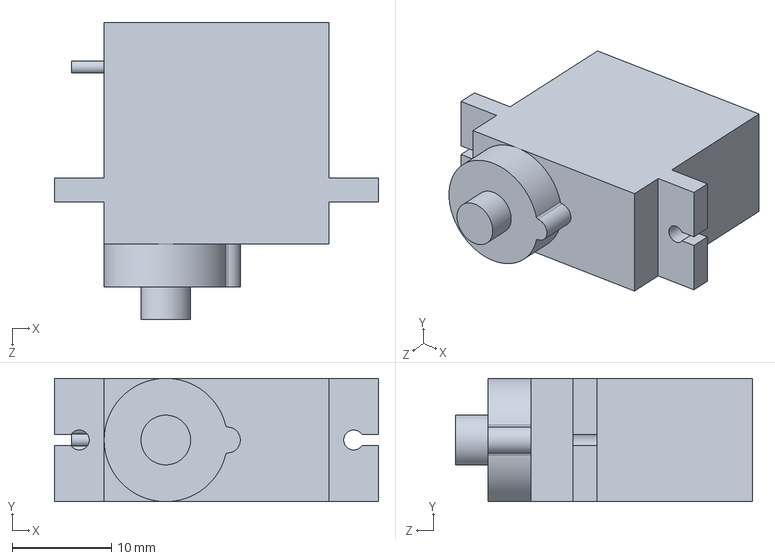
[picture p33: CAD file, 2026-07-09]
CAD/SolidWorks/Parts/Servo Motor Micro 9g.SLDPRT
32.6 x 12.4 x 29.9 mm

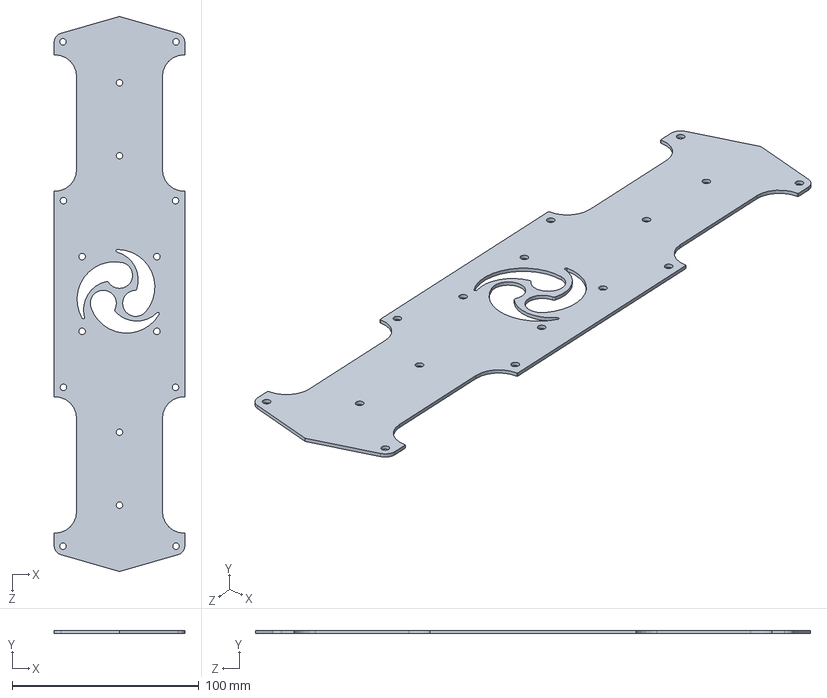
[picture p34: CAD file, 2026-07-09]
CAD/SolidWorks/Parts/üst sac.step.SLDPRT
70.0 x 1.50 x 297.1 mm

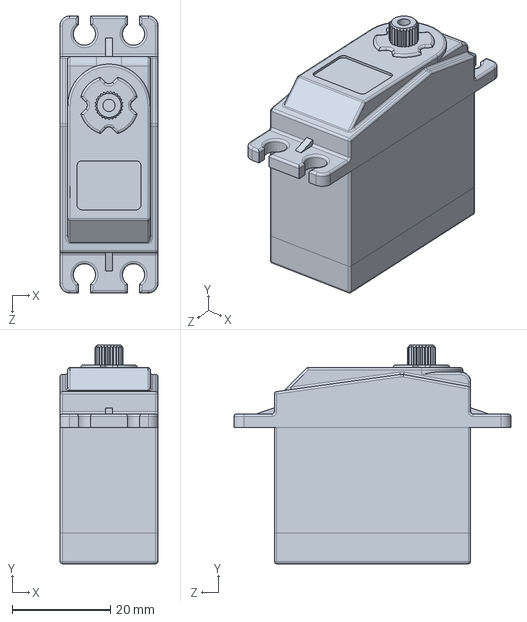
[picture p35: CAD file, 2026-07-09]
CAD/SolidWorks/Parts/spt5435LV.step.SLDPRT
20.0 x 44.5 x 56.4 mm

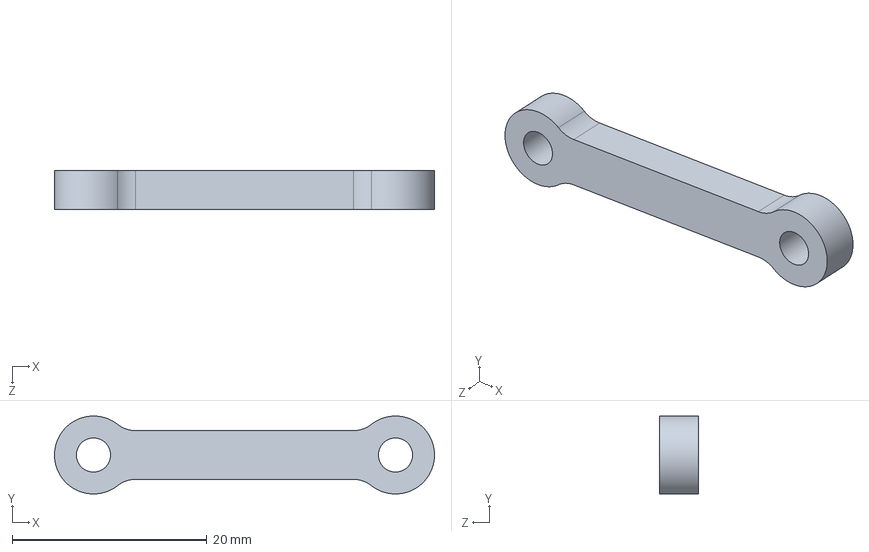
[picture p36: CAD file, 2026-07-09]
CAD/SolidWorks/Parts/Gripper Link.SLDPRT
39.0 x 8.00 x 4.00 mm

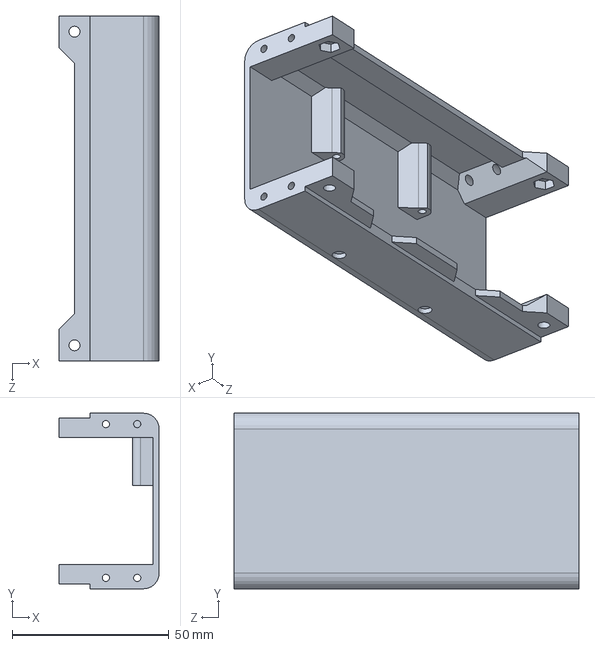
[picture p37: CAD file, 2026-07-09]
CAD/SolidWorks/Parts/gövde1-V2.step.SLDPRT
32.0 x 56.0 x 110.0 mm

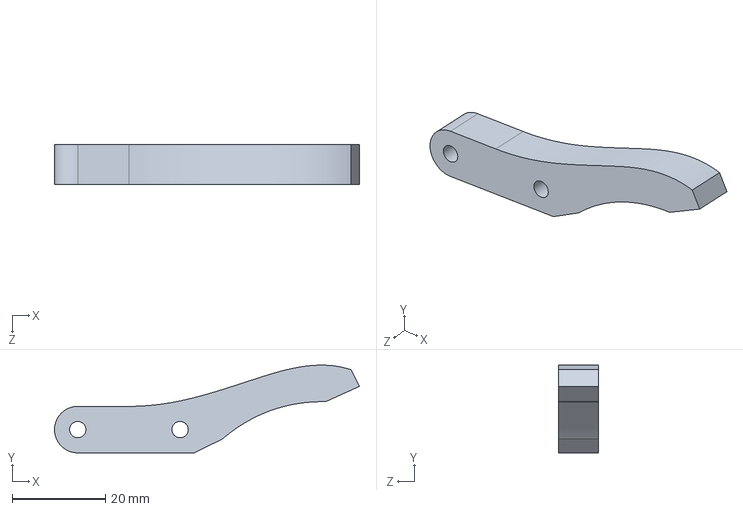
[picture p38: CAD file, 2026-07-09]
CAD/SolidWorks/Parts/Gripper.SLDPRT
65.6 x 18.9 x 8.50 mm

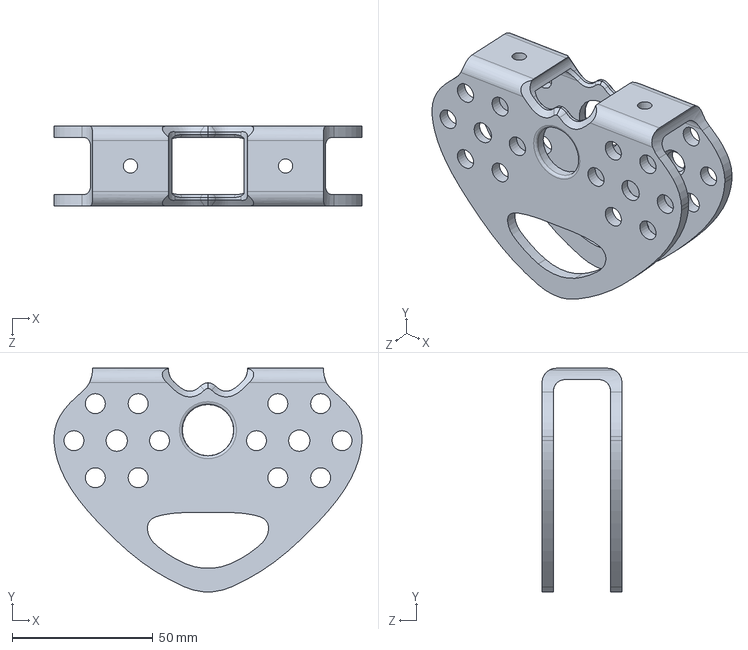
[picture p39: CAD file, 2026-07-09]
CAD/SolidWorks/Parts/houder katrol.SLDPRT
109.4 x 79.4 x 28.4 mm

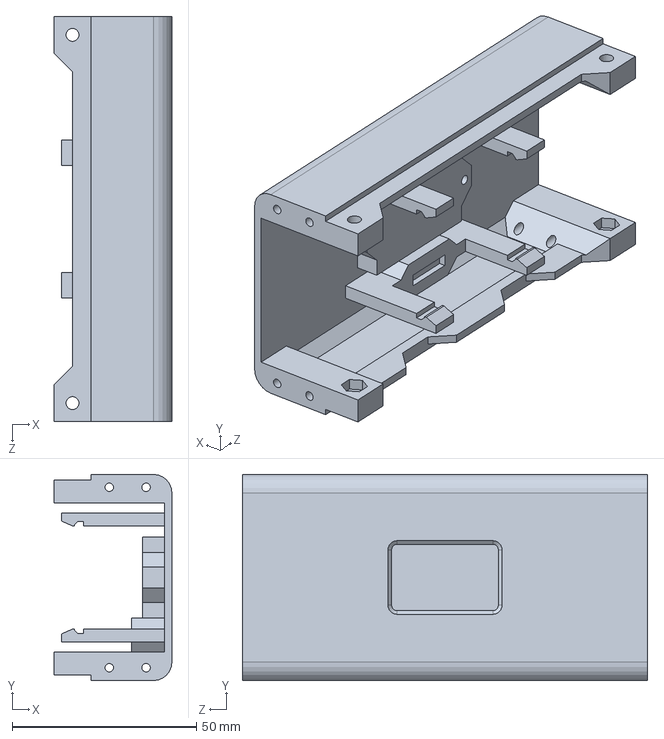
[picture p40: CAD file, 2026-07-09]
CAD/SolidWorks/Parts/gövde2-V2.step.SLDPRT
32.0 x 56.0 x 110.0 mm

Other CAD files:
CAD/SolidWorks/Assemblies/kattol.SLDASM
CAD/SolidWorks/Parts/Robot Gripper Design.SLDPRT
CAD/SolidWorks/Parts/ön1-V2.step.SLDPRT
CAD/SolidWorks/Parts/Parça44.SLDPRT
CAD/SolidWorks/Parts/ARKA1-V2-SWITCH.step.SLDPRT
CAD/SolidWorks/Parts/Arm 01.SLDPRT
CAD/SolidWorks/Parts/Arm 02.SLDPRT
CAD/SolidWorks/Parts/Arm 03.SLDPRT
CAD/SolidWorks/Parts/Base of Robotic Arm.SLDPRT
CAD/SolidWorks/Parts/Gear 1.SLDPRT
CAD/SolidWorks/Parts/Gear 2.SLDPRT
CAD/SolidWorks/Parts/Nut M3(3.5mm)(5mm).SLDPRT
CAD/SolidWorks/Parts/Nut M3(3.5mm)(6mm).SLDPRT
CAD/SolidWorks/Parts/Nut M3(4.25mm).SLDPRT
CAD/SolidWorks/Parts/as.SLDPRT
CAD/SolidWorks/Parts/countersunk raised head cross recess screw_iso.SLDPRT
CAD/SolidWorks/Parts/glijlager.SLDPRT
CAD/SolidWorks/Parts/hex screw gradeab_iso.SLDPRT
CAD/SolidWorks/Parts/hex thin nut gradeb_iso.SLDPRT
CAD/SolidWorks/Parts/pan head cross recess screw_iso.SLDPRT
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

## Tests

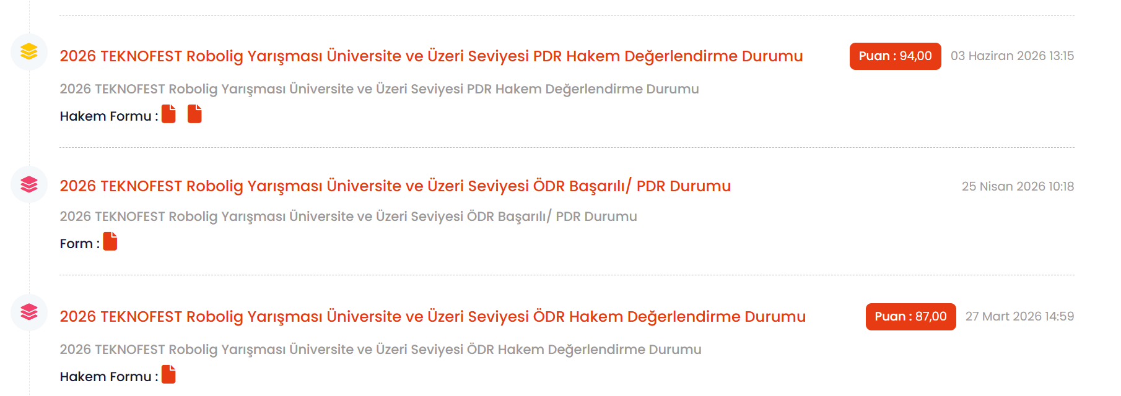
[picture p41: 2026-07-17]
Documents/TEKNOFEST/Evaluation_Results/image.png

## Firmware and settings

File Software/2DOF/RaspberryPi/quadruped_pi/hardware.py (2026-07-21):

"""
hardware.py
===========
PCA9685 + DS3235 servo kontrol katmani.

config.py ile uyumlu guncel surum.
"""

from __future__ import annotations

import time
from typing import Dict, Optional

import config


# =============================================================================
# PCA9685 / SERVO AYARLARI - config.py ile uyumlu
# =============================================================================
PCA9685_ADDRESS = config.PCA9685_I2C_ADDRESS
PCA9685_CHANNELS = 16

SERVO_FREQ_HZ = config.PCA9685_FREQ_HZ

SERVO_MIN_PULSE_US = config.SERVO_PULSE_MIN_US
SERVO_MAX_PULSE_US = config.SERVO_PULSE_MAX_US
SERVO_ACTUATION_RANGE_DEG = int(config.SERVO_RANGE_DEG)

SERVO_MIN_ANGLE_DEG = config.SERVO_MIN_ANGLE_DEG
SERVO_MAX_ANGLE_DEG = config.SERVO_MAX_ANGLE_DEG

DEFAULT_SERVO_CENTER_DEG = 90.0
COMMAND_DELAY_S = getattr(config, "HARDWARE_COMMAND_DELAY_S", 0.0)


# =============================================================================
# Yardimci fonksiyonlar
# =============================================================================
def _nested_get(mapping_name: str, leg: int, joint: int, default):
    mapping = getattr(config, mapping_name, None)

    if mapping is None:
        return default

    try:
        return mapping[leg][joint]
    except Exception:
        return default


class HardwareController:
    """
    real=False:
        Simulasyon modu. Servo surmez, sadece komutlari ekrana yazar.

    real=True:
        Raspberry Pi + PCA9685 uzerinden gercek servo surer.
    """

    def __init__(self, real: bool = False, verbose: bool = True):
        self.real = bool(real)
        self.verbose = bool(verbose)

        self.kit = None
        self.last_servo_angles: Dict[int, float] = {}

        if self.real:
            self._init_real_hardware()
        else:
            if self.verbose:
                print(">>> HardwareController SIM mode.")
                print(">>> Gercek servo surulmuyor, sadece komutlar yazdirilir.")

    # -------------------------------------------------------------------------
    # Initialization
    # -------------------------------------------------------------------------
    def _init_real_hardware(self) -> None:
        try:
            from adafruit_servokit import ServoKit

            self.kit = ServoKit(
                channels=PCA9685_CHANNELS,
                address=PCA9685_ADDRESS,
            )

            for channel in self._used_channels():
                servo = self.kit.servo[channel]
                servo.set_pulse_width_range(
                    SERVO_MIN_PULSE_US,
                    SERVO_MAX_PULSE_US,
                )
                servo.actuation_range = SERVO_ACTUATION_RANGE_DEG

            if self.verbose:
                print(">>> PCA9685 baglantisi basarili.")
                print(f">>> Address: 0x{PCA9685_ADDRESS:02X}")
                print(f">>> Servo freq: {SERVO_FREQ_HZ} Hz")
                print(f">>> Pulse range: {SERVO_MIN_PULSE_US}-{SERVO_MAX_PULSE_US} us")
                print(f">>> Actuation range: {SERVO_ACTUATION_RANGE_DEG} deg")
                print(f">>> Used channels: {self._used_channels()}")

        except Exception as exc:
            self.kit = None
            self.real = False
            print(f">>> PCA9685/ServoKit baslatilamadi: {exc}")
            print(">>> SIM mode'a gecildi. Servo surulmuyor.")

    def _used_channels(self):
        channels = []

        for leg in range(config.NUM_LEGS):
            for joint in range(config.NUM_JOINTS):
                channel = config.SERVO_CHANNELS[leg][joint]
                channels.append(channel)

        return sorted(set(channels))

    # -------------------------------------------------------------------------
    # Angle conversion
    # -------------------------------------------------------------------------
    def ik_to_servo_angle(self, leg: int, joint: int, ik_angle_deg: float) -> float:
        """
        IK acisini servo acisina cevirir.

        Formul:
            servo_angle = center + direction * ik_angle + offset
        """
        center = _nested_get("SERVO_CENTER", leg, joint, DEFAULT_SERVO_CENTER_DEG)
        direction = _nested_get("SERVO_DIRECTION", leg, joint, +1)
        offset = _nested_get("SERVO_OFFSET", leg, joint, 0.0)

        servo_angle = center + direction * ik_angle_deg + offset
        servo_angle = self._clamp(
            servo_angle,
            SERVO_MIN_ANGLE_DEG,
            SERVO_MAX_ANGLE_DEG,
        )

        return servo_angle

    # -------------------------------------------------------------------------
    # Public servo commands
    # -------------------------------------------------------------------------
    def set_joint_angle(self, leg: int, joint: int, ik_angle_deg: float) -> float:
        channel = config.SERVO_CHANNELS[leg][joint]
        servo_angle = self.ik_to_servo_angle(leg, joint, ik_angle_deg)

        self.last_servo_angles[channel] = servo_angle

        if self.real and self.kit is not None:
            self.kit.servo[channel].angle = servo_angle
            if self.verbose:
                print(
                    f"[REAL] {config.LEG_NAMES[leg]} "
                    f"{self._joint_name(joint):>4} | "
                    f"IK={ik_angle_deg:+8.2f} deg -> "
                    f"servo={servo_angle:7.2f} deg | "
                    f"channel={channel}"
                )
        else:
            if self.verbose:
                print(
                    f"[SIM] {config.LEG_NAMES[leg]} "
                    f"{self._joint_name(joint):>4} | "
                    f"IK={ik_angle_deg:+8.2f} deg -> "
                    f"servo={servo_angle:7.2f} deg | "
                    f"channel={channel}"
                )

        if COMMAND_DELAY_S > 0.0:
            time.sleep(COMMAND_DELAY_S)

        return servo_angle

    def set_servo_angle_direct(self, channel: int, angle_deg: float) -> float:
        """
        IK donusumu yapmadan dogrudan servo acisi yollar.
        Neutral/horn kalibrasyonu icin kullanilir.
        """
        angle = self._clamp(angle_deg, SERVO_MIN_ANGLE_DEG, SERVO_MAX_ANGLE_DEG)
        self.last_servo_angles[channel] = angle

        if self.real and self.kit is not None:
            self.kit.servo[channel].angle = angle
            if self.verbose:
                print(f"[REAL] direct servo={angle:7.2f} deg | channel={channel}")
        else:
            if self.verbose:
                print(f"[SIM] direct servo={angle:7.2f} deg | channel={channel}")

        return angle

    def set_leg_angles(
        self,
        leg: int,
        hip_deg: Optional[float],
        knee_deg: Optional[float],
    ) -> None:
        if hip_deg is None or knee_deg is None:
            if self.verbose:
                print(f">>> {config.LEG_NAMES[leg]} hedef acisi None, komut atlandi.")
            return

        self.set_joint_angle(leg, config.JOINT_HIP, hip_deg)
        self.set_joint_angle(leg, config.JOINT_KNEE, knee_deg)

    def apply_targets(self, targets) -> None:
        for leg, target in targets.items():
            if not getattr(target, "reachable", False):
                if self.verbose:
                    print(f">>> {config.LEG_NAMES[leg]} reachable=False, komut atlandi.")
                continue

            self.set_leg_angles(
                leg=leg,
                hip_deg=target.hip_deg,
                knee_deg=target.knee_deg,
            )

    def stand_all_neutral(self) -> None:
        for leg in range(config.NUM_LEGS):
            for joint in range(config.NUM_JOINTS):
                channel = config.SERVO_CHANNELS[leg][joint]
                center = _nested_get("SERVO_CENTER", leg, joint, DEFAULT_SERVO_CENTER_DEG)
                self.set_servo_angle_direct(channel, center)

    def release_all(self) -> None:
        for channel in self._used_channels():
            if self.real and self.kit is not None:
                self.kit.servo[channel].angle = None

            if self.verbose:
                print(f">>> channel {channel} PWM released")

    # -------------------------------------------------------------------------
    # Helpers
    # -------------------------------------------------------------------------
    @staticmethod
    def _clamp(value: float, lower: float, upper: float) -> float:
        if value < lower:
            return lower
        if value > upper:
            return upper
        return value

    @staticmethod
    def _joint_name(joint: int) -> str:
        if joint == config.JOINT_HIP:
            return "HIP"
        if joint == config.JOINT_KNEE:
            return "KNEE"
        return f"J{joint}"


if __name__ == "__main__":
    from quadruped import QuadRuped

    dog = QuadRuped()
    hw = HardwareController(real=False, verbose=True)

    print("\n>>> STAND hedefleri SIM olarak uygulanıyor")
    dog.stand()
    targets = dog.update(dt=0.02)
    hw.apply_targets(targets)

    print("\n>>> WALK hedefleri SIM olarak uygulanıyor")
    dog.walk(speed_scale=1.0)

    for i in range(3):
        print(f"\n--- walk step {i + 1} ---")
        targets = dog.update(dt=0.02)
        hw.apply_targets(targets)

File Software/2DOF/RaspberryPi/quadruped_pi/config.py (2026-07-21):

"""
config.py - BUYUK KOPEK (1.8x olcek)
=====================================
Borutay quadruped robot - merkezi konfigurasyon.
Tum sabitler burada, diger dosyalar bunu import eder.

BASKI %180 (1.8x) BUYUTULDU: tum mm degerleri eski config x 1.8.
Acilar ve IK matematigi AYNI (geometrik benzerlik - ucgen buyuyunce
acilari degismez). Sadece uzunluk/yukseklik/adim degerleri olceklendi.
"""

# =============================================================================
# BACAK GEOMETRISI (mm) - 1.8x olcek
# =============================================================================
# Eski STL olculeri x 1.8
FEMUR_LENGTH = 190.46       # ust bacak (eski 105.81 x 1.8)
TIBIA_LENGTH = 159.53       # alt bacak (eski  88.63 x 1.8)

# Govde geometrisi (mm) - 1.8x
BODY_LENGTH = 396.0         # on hip ile arka hip arasi (eski 220 x 1.8)
BODY_WIDTH = 198.0          # sol hip ile sag hip arasi (eski 110 x 1.8)
BODY_STAND_HEIGHT = 288.0   # ayak ucundan govde tabanina (eski 160 x 1.8)
BODY_IDLE_HEIGHT = 234.0    # cromelmis poz (eski 130 x 1.8)

# =============================================================================
# BACAK INDEKSLEME
# =============================================================================
LEG_RF = 0  # Right Front  (Sag On)
LEG_RH = 1  # Right Hind   (Sag Arka)
LEG_LH = 2  # Left Hind    (Sol Arka)
LEG_LF = 3  # Left Front   (Sol On)
NUM_LEGS = 4
LEG_NAMES = ["RF", "RH", "LH", "LF"]


def is_front_leg(leg):
    """Bacak on bacak mi?"""
    return leg == LEG_RF or leg == LEG_LF


def is_right_leg(leg):
    """Bacak sag bacak mi?"""
    return leg == LEG_RF or leg == LEG_RH


# =============================================================================
# EKLEM INDEKSLEME
# =============================================================================
JOINT_HIP = 0   # ust eklem (kalca)
JOINT_KNEE = 1  # alt eklem (diz)
NUM_JOINTS = 2  # her bacakta 2 servo (2-DOF)

# Eklem aci limitleri (derece) - IK hesabi icin
HIP_MIN_DEG = -65.0
HIP_MAX_DEG = +65.0
KNEE_MIN_DEG = -120.0
KNEE_MAX_DEG = +10.0

# =============================================================================
# SERVO CHANNEL MAPPING (PCA9685)
# =============================================================================
# Her bacagin (hip_channel, knee_channel) PCA9685 kanal numarasi.
SERVO_CHANNELS = {
    LEG_RF: (0, 1),   # Sag On  : hip=0, knee=1
    LEG_RH: (2, 3),   # Sag Arka: hip=2, knee=3
    LEG_LH: (4, 5),   # Sol Arka: hip=4, knee=5
    LEG_LF: (6, 7),   # Sol On  : hip=6, knee=7
}

# =============================================================================
# SERVO KALIBRASYON (her servo icin ayri ayarlanir)
# =============================================================================
# Mekanik nötr konumda servo'nun gerçek açi degeri (derece).
# 180-derece servo icin orta = 90. Horn'u 90'da takmadiysan burada ayarla.
#
# YENI BUYUK KOPEK MONTAJI: horn'lar yeni takiliyor. Once servo_kalibre.py
# ile 'all 90' yapip horn'lari stand pozisyonunda tak, sonra find_neutrals.py
# ile ince ayar yapip cikan degerleri buraya yapistir.
#
# Baslangic olarak hepsi 90 (yeni montaj icin notr). Kalibrasyon sonrasi
# guncellenecek.
SERVO_CENTER = {
    LEG_RF: {JOINT_HIP: 90.0, JOINT_KNEE: 90.0},
    LEG_RH: {JOINT_HIP: 90.0, JOINT_KNEE: 90.0},
    LEG_LH: {JOINT_HIP: 90.0, JOINT_KNEE: 90.0},
    LEG_LF: {JOINT_HIP: 90.0, JOINT_KNEE: 90.0},
}

# Servo donus yonu: +1 normal, -1 ters.
# Sol bacaklar genelde sag bacaklarin aynasi oldugu icin ters donmesi gerekir.
SERVO_DIRECTION = {
    LEG_RF: {JOINT_HIP: +1, JOINT_KNEE: +1},
    LEG_RH: {JOINT_HIP: +1, JOINT_KNEE: +1},
    LEG_LH: {JOINT_HIP: -1, JOINT_KNEE: -1},
    LEG_LF: {JOINT_HIP: -1, JOINT_KNEE: -1},
}

# Horn'u takarken olusan kucuk mekanik kayma icin offset (derece).
# Kalibrasyon sirasinda her bacak icin elle ayarlanir.
SERVO_OFFSET = {
    LEG_RF: {JOINT_HIP: 0.0, JOINT_KNEE: 0.0},
    LEG_RH: {JOINT_HIP: 0.0, JOINT_KNEE: 0.0},
    LEG_LH: {JOINT_HIP: 0.0, JOINT_KNEE: 0.0},
    LEG_LF: {JOINT_HIP: 0.0, JOINT_KNEE: 0.0},
}

# =============================================================================
# PCA9685 + SERVO PARAMETRELERI
# =============================================================================
# DS3235 standart hobby PWM: 500-2500 us pulse, 50 Hz frame.
PCA9685_I2C_ADDRESS = 0x40       # varsayilan adres
PCA9685_FREQ_HZ = 50              # servo refresh rate

SERVO_PULSE_MIN_US = 500          # bir uca karsilik gelir
SERVO_PULSE_MAX_US = 2500         # diger uca karsilik gelir
SERVO_RANGE_DEG = 180.0           # DS3235 180-derece versiyon

# Servo komut acisi guvenlik sinirlari (PCA9685'e gonderilen)
SERVO_MIN_ANGLE_DEG = 0.0
SERVO_MAX_ANGLE_DEG = 180.0

# =============================================================================
# KONTROL DONGUSU
# =============================================================================
CONTROL_LOOP_HZ = 50
CONTROL_LOOP_DT = 1.0 / CONTROL_LOOP_HZ  # = 0.02 s
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

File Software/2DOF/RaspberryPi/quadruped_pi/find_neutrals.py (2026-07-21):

"""
find_neutrals.py
================
Her bacagin hip ve knee servosu icin "stand pose" notr aci bulma rutini.

NE YAPAR:
    Her 8 servoyu sirayla acar, sen "+" / "-" tuslariyla bacak
    DIK ve DENGELI duruncaya kadar ayarlarsin. Buldugun degerleri
    config.py'deki SERVO_CENTER'a kopyalayabilirsin.

KULLANIM:
    1. Robot bir destege yaslanmis veya askida olsun (yere temas etmesin)
    2. python find_neutrals.py
    3. Her servo icin:
        - Servo SERVO_CENTER'daki mevcut degere gider
        - Sen tuslarla ayarlarsin:
            + veya =   -> +1 derece
            -          -> -1 derece
            ++         -> +5 derece
            --         -> -5 derece
            ok / Enter -> bu deger kabul, sonraki servoya gec
            skip       -> bu servoyu atla, eskisi kalsin
            q          -> cikis, buraya kadar bulduklarini yazdir

ONERILEN BASLANGIC POZISYONU (stand pose):
    HIP servo  : bacak dik asagi baksin (femur dikine inde)
    KNEE servo : tibia femure 90 derecede olsun (klasik stand)

CIKTI:
    Tum servolar gezildikten sonra ekrana config.py icin yapistirilacak
    format'ta SERVO_CENTER bloku basilir.
"""

import sys

import config
from adafruit_servokit import ServoKit


def main():
    print("=" * 70)
    print(" SERVO NOTR BULMA")
    print("=" * 70)
    print()
    print(" Her servo icin tuslar:")
    print("   +  =>  +1 derece")
    print("   ++ =>  +5 derece")
    print("   -  =>  -1 derece")
    print("   -- =>  -5 derece")
    print("   <sayi>  =>  o aciya direkt git (orn: 95)")
    print("   ok  veya Enter  =>  bu deger kabul, sonraki servoya gec")
    print("   skip => bu servoyu atla")
    print("   q   =>  cikis, buraya kadarini bas")
    print()
    print(" ROBOT ASKIDA OLSUN. Bacaklar yere basmasin.")
    print("=" * 70)
    print()

    input("Hazirsan Enter'a bas... ")

    # PCA9685
    try:
        kit = ServoKit(channels=16, address=config.PCA9685_I2C_ADDRESS)
    except Exception as exc:
        print(f"HATA: PCA9685 baglantisi: {exc}")
        return 1

    # Servo kanallarini hazirla
    for leg in range(config.NUM_LEGS):
        for joint in range(config.NUM_JOINTS):
            ch = config.SERVO_CHANNELS[leg][joint]
            kit.servo[ch].set_pulse_width_range(
                config.SERVO_PULSE_MIN_US,
                config.SERVO_PULSE_MAX_US,
            )
            kit.servo[ch].actuation_range = int(config.SERVO_RANGE_DEG)

    # Mevcut SERVO_CENTER degerlerinden basla
    found = {}
    for leg in range(config.NUM_LEGS):
        found[leg] = {}
        for joint in range(config.NUM_JOINTS):
            found[leg][joint] = config.SERVO_CENTER[leg][joint]

    # Her bacak/eklem icin tek tek
    leg_order = [config.LEG_RF, config.LEG_RH, config.LEG_LH, config.LEG_LF]
    joint_order = [config.JOINT_HIP, config.JOINT_KNEE]

    quit_requested = False

    for leg in leg_order:
        if quit_requested:
            break
        for joint in joint_order:
            if quit_requested:
                break

            leg_name = config.LEG_NAMES[leg]
            joint_name = "HIP" if joint == config.JOINT_HIP else "KNEE"
            channel = config.SERVO_CHANNELS[leg][joint]
            angle = found[leg][joint]

            print()
            print("=" * 70)
            print(f"  Sira: {leg_name}-{joint_name}  (kanal {channel})")
            print(f"  Baslangic aci: {angle:.1f} derece")
            print("=" * 70)

            # Servoyu mevcut acya getir
            kit.servo[channel].angle = clamp(angle, 0.0, 180.0)
            print(f"  Servo {angle:.1f} dereceye gitti.")
            print()
            if joint == config.JOINT_HIP:
                print("  HEDEF: femur (ust bacak) govdeden dik asagi baksin")
            else:
                print("  HEDEF: tibia (alt bacak) femure 90 derecede,")
                print("         ayak ucu dogrudan altta olsun")
            print()

            while True:
                try:
                    cmd = input(f"  [{leg_name}-{joint_name} @ {angle:.1f}] > ").strip().lower()
                except (EOFError, KeyboardInterrupt):
                    quit_requested = True
                    break

                if cmd in ("q", "quit"):
                    quit_requested = True
                    break

                if cmd in ("ok", "", "n", "next"):
                    found[leg][joint] = angle
                    print(f"  ✓ {leg_name}-{joint_name} = {angle:.1f} kaydedildi")
                    break

                if cmd in ("skip", "s"):
                    print(f"  → {leg_name}-{joint_name} atlandi, eski deger: {found[leg][joint]:.1f}")
                    break

                # Delta komutlari
                if cmd == "+" or cmd == "=":
                    angle = clamp(angle + 1.0, 0.0, 180.0)
                elif cmd == "-":
                    angle = clamp(angle - 1.0, 0.0, 180.0)
                elif cmd == "++":
                    angle = clamp(angle + 5.0, 0.0, 180.0)
                elif cmd == "--":
                    angle = clamp(angle - 5.0, 0.0, 180.0)
                else:
                    # Sayisal mutlak deger?
                    try:
                        new_angle = float(cmd)
                        angle = clamp(new_angle, 0.0, 180.0)
                    except ValueError:
                        print("  Komut anlasilmadi. + - ++ -- ok skip q veya sayi")
                        continue

                kit.servo[channel].angle = angle
                print(f"  → {angle:.1f} derece")

    # Cikti: config.py'ye yapistirilacak format
    print()
    print("=" * 70)
    print(" SONUCLAR")
    print("=" * 70)
    print()
    print("Bunu config.py'deki SERVO_CENTER blokunun yerine yapistir:")
    print()
    print("SERVO_CENTER = {")
    for leg in leg_order:
        leg_name = config.LEG_NAMES[leg]
        hip = found[leg][config.JOINT_HIP]
        knee = found[leg][config.JOINT_KNEE]
        print(f"    LEG_{leg_name}: {{JOINT_HIP: {hip:.1f}, JOINT_KNEE: {knee:.1f}}},  # {leg_name}")
    print("}")
    print()

    # Servolari serbest birak
    print("Servolar serbest birakiliyor...")
    for leg in range(config.NUM_LEGS):
        for joint in range(config.NUM_JOINTS):
            ch = config.SERVO_CHANNELS[leg][joint]
            try:
                kit.servo[ch].angle = None
            except Exception:
                pass

    print("Bitti.")
    return 0


def clamp(value, lower, upper):
    if value < lower:
        return lower
    if value > upper:
        return upper
    return value


if __name__ == "__main__":
    sys.exit(main())

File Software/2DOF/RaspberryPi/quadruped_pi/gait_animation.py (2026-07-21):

"""
gait_animation.py
Kopek ekranda duz ileri yuruyor: yer sabit, govde X yonunde ilerler.
Bu sayede robotun gercek yuruyus hareketi daha net gorulur.
"""

import math
import matplotlib.pyplot as plt
import matplotlib.animation as animation

import config
from leg import inverse_kinematics
from gait import GaitTrot


# Dizlerin ice kirildigi taraf kopegin onu kabul edildi.
# Bu animasyonda kopegin onu SOL taraftir.
HIP_X_OFFSETS = {
    config.LEG_RF: -config.BODY_LENGTH / 2.0,
    config.LEG_LF: -config.BODY_LENGTH / 2.0,
    config.LEG_RH: +config.BODY_LENGTH / 2.0,
    config.LEG_LH: +config.BODY_LENGTH / 2.0,
}

LEG_STYLE = {
    config.LEG_RF: {"linestyle": "-",  "alpha": 1.0, "label": "RF"},
    config.LEG_RH: {"linestyle": "-",  "alpha": 1.0, "label": "RH"},
    config.LEG_LF: {"linestyle": "--", "alpha": 0.5, "label": "LF"},
    config.LEG_LH: {"linestyle": "--", "alpha": 0.5, "label": "LH"},
}


def compute_leg_geometry(hip_x, foot_x_local, foot_z_local):
    hip_deg, knee_deg = inverse_kinematics(foot_x_local, foot_z_local)

    if hip_deg is None:
        return (hip_x, 0), (hip_x, 0), (hip_x, 0)

    L1 = config.FEMUR_LENGTH
    L2 = config.TIBIA_LENGTH

    hip_rad = math.radians(hip_deg)
    knee_rad = math.radians(knee_deg)

    hip_pos = (hip_x, 0)

    knee_pos = (
        hip_x + L1 * math.cos(hip_rad),
        L1 * math.sin(hip_rad)
    )

    foot_pos = (
        knee_pos[0] + L2 * math.cos(hip_rad + knee_rad),
        knee_pos[1] + L2 * math.sin(hip_rad + knee_rad)
    )

    return hip_pos, knee_pos, foot_pos


# =============================================================================
# ANIMATION SETTINGS
# =============================================================================
GAIT_PERIOD_S = config.GAIT_PERIOD_S
STEP_LENGTH = config.GAIT_STEP_LENGTH_X
FORWARD_VELOCITY_MM_S = STEP_LENGTH / GAIT_PERIOD_S

FPS = 30
DT = 1.0 / FPS

# False: kopek ekranda ileri yurur, yer sabit kalir.
# True: eski mod; kamera kopegi takip eder, govde sabit kalir.
CAMERA_FOLLOW = False

# Kopek ekrani gecince basa sarma mesafesi.
TRACK_LENGTH = 520


# =============================================================================
# FIGURE SETUP
# =============================================================================
fig, ax = plt.subplots(figsize=(13, 7))
gait = GaitTrot()

body_line, = ax.plot([], [], "k-", linewidth=6, label="Govde")

leg_lines = {}

for leg in [config.LEG_RF, config.LEG_RH, config.LEG_LF, config.LEG_LH]:
    style = LEG_STYLE[leg]
    color = "blue" if config.is_front_leg(leg) else "red"

    femur_line, = ax.plot(
        [],
        [],
        color=color,
        linestyle=style["linestyle"],
        alpha=style["alpha"],
        linewidth=3,
        label=f"{style['label']} femur"
    )

    tibia_line, = ax.plot(
        [],
        [],
        color="orange",
        linestyle=style["linestyle"],
        alpha=style["alpha"],
        linewidth=3
    )

    foot_dot, = ax.plot(
        [],
        [],
        "ko",
        alpha=style["alpha"],
        markersize=10
    )

    leg_lines[leg] = (femur_line, tibia_line, foot_dot)


# Zemin cizgisi
ax.axhline(
    y=-config.BODY_STAND_HEIGHT,
    color="brown",
    linestyle="-",
    alpha=0.6,
    linewidth=2
)

# Zemin uzerindeki sabit kisa isaretler
ground_marks = []

for i in range(40):
    line, = ax.plot([], [], color="saddlebrown", linewidth=2, alpha=0.5)
    ground_marks.append(line)


# Hareket yonu oku
ax.annotate(
    "",
    xy=(-220, 50),
    xytext=(-150, 50),
    arrowprops=dict(arrowstyle="->", color="green", lw=3)
)

ax.text(
    -260,
    65,
    "Kopek bu yone yuruyor",
    color="green",
    fontsize=11,
    fontweight="bold"
)


ax.set_xlim(-280, 280)
ax.set_ylim(-200, 90)
ax.set_aspect("equal")
ax.grid(True, alpha=0.2)
ax.set_xlabel("X (mm)")
ax.set_ylabel("Z (mm, yukari+)")
ax.set_title("Quadruped Trot Gait Animation - Straight Walking View")
ax.legend(loc="lower left", fontsize=8, ncol=3)

info_text = ax.text(
    -270,
    60,
    "",
    fontsize=10,
    family="monospace",
    bbox=dict(facecolor="lightyellow", edgecolor="black")
)


# =============================================================================
# ANIMATION LOOP
# =============================================================================
def animate(frame):
    t_global = frame * DT
    t = (t_global / GAIT_PERIOD_S) % 1.0

    # Kopegin onu sol taraf oldugu icin ileri hareket -X yonundedir.
    body_world_x = -FORWARD_VELOCITY_MM_S * t_global

    if CAMERA_FOLLOW:
        body_screen_x = 0.0
    else:
        body_screen_x = (body_world_x % TRACK_LENGTH) - TRACK_LENGTH / 2.0

    # Govde cizimi
    body_line.set_data(
        [
            body_screen_x - config.BODY_LENGTH / 2.0,
            body_screen_x + config.BODY_LENGTH / 2.0
        ],
        [0, 0]
    )

    # Zemin isaretleri
    floor_y = -config.BODY_STAND_HEIGHT
    spacing = 40

    for i, line in enumerate(ground_marks):
        world_marker_x = (i - 20) * spacing

        if CAMERA_FOLLOW:
            screen_x = world_marker_x - (body_world_x % spacing)
        else:
            screen_x = world_marker_x

        if -280 <= screen_x <= 280:
            line.set_data([screen_x, screen_x], [floor_y - 8, floor_y - 2])
        else:
            line.set_data([], [])

    # Bacaklar
    for leg in [config.LEG_RF, config.LEG_RH, config.LEG_LF, config.LEG_LH]:
        foot_x_local, foot_z_local = gait.foot_position(leg, t)

        hip_pos, knee_pos, foot_pos = compute_leg_geometry(
            body_screen_x + HIP_X_OFFSETS[leg],
            foot_x_local,
            foot_z_local
        )

        femur_line, tibia_line, foot_dot = leg_lines[leg]

        femur_line.set_data(
            [hip_pos[0], knee_pos[0]],
            [hip_pos[1], knee_pos[1]]
        )

        tibia_line.set_data(
            [knee_pos[0], foot_pos[0]],
            [knee_pos[1], foot_pos[1]]
        )

        foot_dot.set_data([foot_pos[0]], [foot_pos[1]])

    rf_x, rf_z = gait.foot_position(config.LEG_RF, t)
    in_air = "HAVADA" if rf_z > -config.BODY_STAND_HEIGHT + 0.5 else "YERDE"

    info_text.set_text(
        f"t = {t:.2f}\n"
        f"Govde dunya X: {body_world_x:7.1f} mm\n"
        f"Ekran X:      {body_screen_x:7.1f} mm\n"
        f"Hiz:          {-FORWARD_VELOCITY_MM_S:.1f} mm/s\n"
        f"RF:           {in_air}"
    )

    return ()


anim = animation.FuncAnimation(
    fig,
    animate,
    frames=600,
    interval=int(1000 * DT),
    blit=False,
    repeat=True
)

if CAMERA_FOLLOW:
    print(">>> Kamera takip modu: govde sabit, yer sola kayiyor.")
else:
    print(">>> Dunya modu: yer sabit, kopek ekranda ileri yuruyor.")

plt.show()

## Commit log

2026-07-09 Create .gitkeep
    Create STL folder structure
2026-07-09 Add latest BORUTAY STL files
    [ARKA1-V2-SWITCH.step.SLDPRT, Arm 01.SLDPRT, Arm 02.SLDPRT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]
2026-07-09 Create CAD directory
2026-07-09 Add SolidWorks part files
    [Gripper assembly.SLDASM, Nut M3(3.5mm)(5mm).SLDPRT, Nut M3(3.5mm)(6mm).SLDPRT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]
2026-07-09 Add SolidWorks assembly files
    [Gripper assembly.SLDASM, ROBOT_KOL.SLDASM, kattol.SLDASM]
2026-07-09 Add STEP files
    [BORUTAY_Kolsuz.step]
2026-07-20 Update README.md
    Updated the README.md to reflect current and future features of the BÖRÜTAY robotic platform.
2026-07-21 Create Raspberry Pi
2026-07-21 Scale quadruped robot configuration to 1.8x
    Updated configuration for the quadruped robot to scale dimensions by 1.8x. Adjusted leg geometry, gait parameters, and calibration settings accordingly.

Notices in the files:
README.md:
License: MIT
